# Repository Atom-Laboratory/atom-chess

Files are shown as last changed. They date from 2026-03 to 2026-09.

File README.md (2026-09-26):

# ATOM Chess

ATOM Chess is a research and development project focused on building an autonomous robotic chess system capable of perceiving a physical chessboard, analyzing the current game state, selecting a move, and physically executing it.

The project combines computer vision, chess programming, artificial intelligence, robotics, motion planning, and embedded systems into a single autonomous platform.

## ATOM Laboratory

ATOM Chess is part of **ATOM Laboratory**, a broader research and development initiative focused on the integration of robotics, computer vision, artificial intelligence, software engineering, electronics, and mechanical engineering.

ATOM Laboratory provides the broader research context in which ATOM Chess is developed. Other projects may be developed independently within the laboratory, with their own technical objectives, architectures, and licensing models.

ATOM Chess is one of the laboratory's open-source software projects, while its physical hardware remains proprietary unless explicitly released under a separate hardware license.

## Project Goals

The primary objective of ATOM Chess is to develop a self-contained robotic system capable of:

* Perceiving the physical chessboard through a camera.
* Determining the current board state.
* Detecting changes caused by human moves.
* Representing the position computationally.
* Generating a valid FEN representation.
* Querying a chess engine for the next move.
* Planning the required robotic motion.
* Executing the move on the physical board.
* Verifying the resulting board state.
* Recovering from unexpected situations.

The system is designed with modularity and hardware/software separation in mind, allowing individual subsystems to be developed, tested, and replaced independently.

## Project Leadership

ATOM Chess was conceived and initiated by **Enzo Ribas**, who leads the project’s technical and product development. He is responsible for defining the system architecture, coordinating the multidisciplinary development effort, and contributing across software engineering, computer vision, robotics, electronics, and mechanical systems.

For more information about his work and professional background, visit his [Enzo's LinkedIn profile](https://www.linkedin.com/in/oenzoribas/).

## System Architecture

ATOM Chess is organized into four primary subsystems:

### Vision

The vision subsystem is responsible for converting camera data into structured information about the chessboard.

### Chess Core

The chess core contains the domain model and game-state logic.

The core is intentionally independent of the physical robot and computer-vision implementation.

### Engine and Planning

The planning layer connects the chess domain to the robotic system.

The chess engine is treated as a decision component rather than as part of the board representation itself.

### Motion and Control

The motion subsystem is responsible for physically executing planned operations.

The current architecture separates high-level planning from low-level motor control, allowing computationally intensive logic to remain outside the microcontroller.

## Build

The project uses CMake as its build-system generator.

The supported development environment is Linux.

A typical build configuration is:

```bash
cmake -S . -B build
cmake --build build
```

Tests can be executed through the configured test target or CTest:

```bash
ctest --test-dir build
```

The exact build configuration may vary depending on the target platform and enabled components.

## Project Status

ATOM Chess is under active development.

Current development is focused on establishing a robust software foundation before integrating the complete perception, chess-engine, planning, and robotic-control pipeline.

The architecture is intentionally evolving as the individual subsystems are validated experimentally.

## Research

ATOM Chess is also intended as a research platform. Its modular architecture enables experimentation in areas including:

* Computer vision for structured environments.
* Chess position recognition.
* Automated move detection.
* Chess position representation.
* Chess-engine integration.
* Robotic manipulation.
* Motion planning.
* Inverse kinematics.
* Autonomous system architectures.
* Human-robot interaction.

The platform is designed so that individual components can be benchmarked and replaced without requiring a complete redesign of the system.

## Contributing

ATOM Chess is developed as a collaborative, multidisciplinary project involving software engineers, computer scientists, researchers, and contributors working across computer vision, chess programming, robotics, electronics, mechanical engineering, and related fields.

Contributions may include:

* Bug fixes.
* New features.
* Tests.
* Documentation.
* Refactoring.
* Performance improvements.
* Research implementations.
* Computer vision improvements.
* Chess algorithms.
* Robotics and motion-planning algorithms.

Pull requests should be focused, tested, and clearly describe the motivation, implementation, and testing performed.

All contributions are expected to follow the project's contribution guidelines, coding standards, testing requirements, and architectural conventions.

For information about contributing, see [`CONTRIBUTING.md`](CONTRIBUTING.MD).

Community members are also encouraged to review existing pull requests. Review guidelines and the community review template are available in [`.github/REVIEW_TEMPLATE.md`](.github/REVIEW_TEMPLATE.md).

## Licensing

ATOM Chess uses separate licensing for software and hardware.

### Software

The ATOM Chess software is released under the MIT License.

See [`LICENSE`](LICENSE) for the complete license text.

Unless explicitly stated otherwise, the MIT License applies to the software source code contained in this repository.

### Hardware

The ATOM Chess hardware is currently **not open source**.

Hardware designs are not licensed under the MIT License.

This includes, but is not limited to:

* Mechanical CAD files.
* Mechanical drawings.
* Electrical schematics.
* PCB designs.
* PCB layouts.
* Manufacturing files.
* Bills of materials.
* Assembly documentation.
* Manufacturing documentation.

Unless explicitly stated otherwise, no permission is granted to reproduce, manufacture, modify, distribute, or commercially exploit the ATOM Chess hardware designs.

See [`HARDWARE_LICENSE.md`](HARDWARE_LICENSE.md) for the current hardware licensing policy.

### Third-Party Materials

Third-party software, hardware, documentation, libraries, models, and other materials remain subject to their respective licenses.

The ATOM Chess MIT License does not supersede or replace the license of third-party materials.

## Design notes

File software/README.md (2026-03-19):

<div>

  <h1>Taxonomia</h1>
vision/
board_state/
engine/
motion/
robot/
integration/
config/
tests/

vision/
Tudo que envolve câmera, calibração, homografia, detecção de peças.

board_state/
Representação do tabuleiro. Conversão entre coordenadas de casa (E2) e coordenadas reais (x, y).

engine/
Interface com Stockfish. Nada de lógica física aqui. Só comunicação e interpretação de movimentos.

motion/
Planejamento de trajetórias. Conversão de coordenadas do mundo para pontos que a garra precisa visitar.

robot/
Drivers do SCARA. Comunicação serial, controle de motores, cinemática direta e inversa.

integration/
Onde o sistema todo conversa. Máquina de estados do robô. Aqui você decide: capturar imagem → validar → mover → confirmar.

config/
Parâmetros físicos:

– Altura da câmera
– Matriz de transformação câmera→garra
– Dimensões do tabuleiro
– Limites do SCARA

Nada de valores mágicos espalhados pelo código.

tests/
Testes unitários.
Teste de homografia.
Teste de cinemática inversa.
Teste de conversão casa→coordenada.

Agora algo que pouca gente faz e deveria fazer: versionar calibrações.

Crie uma pasta:

calibration_data/
</div>

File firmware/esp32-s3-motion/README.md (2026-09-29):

# ESP32-S3 Motion Controller Firmware

Reference firmware for the ATOM Chess adaptation of Dejan's How To Mechatronics SCARA.

It receives the host-side ACM1 joint contract:

```
ACM1|<seq>|SEG|<j1_rad>|<j2_rad>|<j3_rad>|<z_mm>|<gripper_pct>|<duration_ms>
```

and controls:

- J1 NEMA 17 through STEP/DIR;
- J2 NEMA 17 through STEP/DIR;
- J3 NEMA 17 through STEP/DIR;
- Z NEMA 17 through STEP/DIR;
- MG996R-compatible gripper servo.

## Safety default

`robot_config.hpp` ships with:

```cpp
configured = false;
```

In this state the firmware boots and parses protocol traffic but replies `ERR|100` to movement commands.

Do not change this flag until all physical values are measured.

## Before enabling motion

Fill:

- STEP/DIR GPIOs for J1/J2/J3/Z;
- endstop GPIOs;
- E-stop GPIO;
- servo GPIO;
- J1/J2/J3 steps per radian;
- Z steps per millimetre;
- motor direction inversion;
- speed/acceleration limits;
- servo pulse limits.

Record the same values in:

`software/acmotion/docs/physical-calibration-template.md`

## Build

Install PlatformIO, then:

```bash
cd firmware/esp32-s3-motion
pio run
pio run -t upload
pio device monitor -b 115200
```

## Bring-up order

1. Build with `configured=false`.
2. Verify serial boot message.
3. Verify endstop/E-stop inputs.
4. Measure and enter pin/conversion configuration.
5. Keep motor power disabled and verify ACM1 parsing.
6. Enable one driver/axis at a time at conservative current and speed.
7. Verify J1, then J2, then J3, then Z.
8. Verify gripper.
9. Verify E-stop/limit interruption.
10. Only then enable full host MotionExecution.

The firmware contains no chess-domain logic and no inverse kinematics.

## Runtime cancellation

Cancellation is polled during active motion, not only between segments.

A matching:

```
ACM1|<active-seq>|CANCEL
```

stops further STEP generation for the active segment and returns a terminal response. Additional SEG commands received while a segment is active are rejected rather than executed re-entrantly.

The physical E-stop must still be wired as an independent hardware safety mechanism; software cancellation is not a substitute for it.

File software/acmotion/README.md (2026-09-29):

# acmotion

`acmotion` is the high-level motion subsystem of ATOM Chess.

It runs primarily on the Linux SBC / Brain and converts validated chess moves into physically executable SCARA motion while keeping low-level motor control on the ESP32-S3.

## Runtime pipeline

```
ac::chess::Move
    ↓
TaskPlanner
    ↓
PhysicalTask[]
    ↓
MotionPlanner
    ↓
Pose[]
    ↓
InverseKinematics
    ↓
JointSegment[]
    ↓
MotionExecution
    ↓
ACM1 / IMotionTransport
    ↓
ESP32-S3
    ↓
interpolation / motion profile / STEP-DIR
```

## Component responsibilities

| Component | Responsibility | Runtime |
| --- | --- | --- |
| CoordinateMapper | Board/graveyard → calibrated XY | Linux SBC |
| GraveyardAllocator | Deterministic captured-piece slot allocation | Linux SBC |
| TaskPlanner | Validated Move → ordered PhysicalTask[] | Linux SBC |
| MotionPlanner | Physical transfer → safe Pose[] | Linux SBC |
| InverseKinematics | Pose → joint-space target | Linux SBC |
| MotionExecution | JointSegment sequencing and controller responses | Linux SBC |
| MotionProtocol | ACM1 encoding/parsing | Linux SBC + compatible firmware |
| ESP32-S3 firmware | Interpolation, profiles, STEP/DIR, limits, E-stop | ESP32-S3 |

## Documentation

Start here for physical integration:

- [Dejan SCARA bring-up manual](docs/dejan-scara-bringup.md)
- [Physical integration runbook](docs/physical-integration-runbook.md)
- [Physical calibration template](docs/physical-calibration-template.md)

Architecture decisions:

- [ADR-002 — SBC/ESP32 boundary](../docs/adrs/ADR-002-acmotion-sbc-esp32-boundary.md)
- [ADR-003 — TaskPlanner/PhysicalTask boundary](../docs/adrs/ADR-003-task-planner-physical-task-boundary.md)
- [ADR-004 — IK on SBC](../docs/adrs/ADR-004-inverse-kinematics-on-sbc.md)
- [ADR-005 — ACM1 protocol](../docs/adrs/ADR-005-acm1-motion-protocol.md)

## Linux quick start

From repository root:

```bash
bash software/acmotion/scripts/setup_linux.sh
bash software/acmotion/scripts/build_and_test.sh
bash software/acmotion/scripts/preflight_linux.sh
```

For a specific serial device:

```bash
bash software/acmotion/scripts/preflight_linux.sh /dev/ttyUSB0
python3 software/acmotion/scripts/serial_monitor.py \
  --device /dev/ttyUSB0 \
  --baud 115200
```

The serial monitor is intentionally read-only.

## Build without ROS2

ROS2/ament remains optional for the MVP motion core.

Repository headless build:

```bash
cmake -S . -B build -G Ninja \
  -DCMAKE_BUILD_TYPE=Debug \
  -DACCHESS_BUILD_VIEWER=OFF \
  -DACVISION_BUILD_HARDWARE_TESTS=OFF

cmake --build build --parallel
ctest --test-dir build --output-on-failure
```

## Rules for contributors

- Do not introduce production mocks into runtime motion code.
- Do not duplicate chess legality in `acmotion`.
- Do not put FEN, Board, PieceType or chess-square semantics in ESP32 firmware.
- Do not hard-code physical SCARA dimensions in the IK solver.
- Do not bypass CoordinateMapper with duplicated physical board constants.
- Keep units explicit in public APIs and Doxygen.
- Hardware-independent tests must remain runnable on CI.
- New hardware/protocol decisions should receive an ADR.

## How To Mechatronics compatibility

The selected physical arm is Dejan's How To Mechatronics SCARA design with J1, J2, J3 and Z driven by four NEMA 17 motors plus an MG996R gripper servo.

The acmotion joint-space contract now represents all four NEMA-driven axes. `Pose.toolYawRad` defines planar end-effector orientation; inverse kinematics solves J1/J2 for XY and derives J3 to maintain that orientation. ACM1 transports J1/J2/J3/Z/gripper.

Physical dimensions, J3 zero offset, joint limits, transmission ratios and motor-direction conventions remain hardware calibration values and must be measured before powered autonomous motion.

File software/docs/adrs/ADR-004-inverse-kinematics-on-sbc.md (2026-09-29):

# ADR-004: Inverse kinematics runs on the Linux SBC

## Status

Proposed for #153 / PR #156.

## Context

The SCARA manipulator requires conversion from Cartesian end-effector poses into joint-space targets before low-level execution.

Placing inverse kinematics in the ESP32 firmware would couple manipulator geometry, frame conventions and workspace policy to the embedded controller. That would make simulation, numerical testing and future geometry changes harder.

## Decision

Run inverse kinematics on the Linux SBC / Brain.

The SBC converts:

```
Pose(x, y, z, gripper, toolYaw)
    ↓
InverseKinematics
    ↓
JointTarget(theta1, theta2, theta3, z, gripper)
```

The ESP32-S3 receives joint-space targets only.

### Geometry

The solver is parameterized by:
- link 1 length in millimetres;
- link 2 length in millimetres;
- joint 1 angular limits in radians;
- joint 2 angular limits in radians;
- joint 3 angular limits in radians;
- joint 3 zero offset in radians;
- Z travel limits in millimetres;
- deterministic elbow configuration.

No project-specific physical dimensions are hard-coded in the solver.

### Model

The planar 2R solution uses:

```
c2 = (x² + y² - L1² - L2²) / (2 L1 L2)
theta2 = ±acos(c2)
theta1 = atan2(y, x) - atan2(L2 sin(theta2), L1 + L2 cos(theta2))
```

The selected elbow branch is explicit and deterministic.

For the distal axis:

```
theta3 = toolYaw - theta1 - theta2 - joint3ZeroOffset
```

This keeps the planar end-effector/camera orientation explicit and independent from the J1/J2 position solution.

## Coordinate-frame assumptions

Before physical use, the team must document and measure:
- SCARA base origin;
- positive X direction;
- positive Y direction;
- positive joint rotation conventions;
- zero/reference angle of each revolute joint;
- positive Z direction;
- tool-center-point offset, if any;
- board plane height relative to Z zero.

These values are hardware configuration, not implementation constants.

## Consequences

IK is testable numerically without the robot.

Manipulator geometry can change without modifying firmware protocol semantics.

The firmware remains simpler and deterministic.

Incorrect frame definitions or CAD measurements can still produce physically unsafe targets, so integration must begin with motor power disabled and then progress through low-speed joint validation.

## Physical validation sequence

1. Measure L1/L2 and joint zero references.
2. Record mechanical joint and Z limits.
3. Validate solver against hand-computed/reference points.
4. With motors disabled, compare generated targets against expected joint values.
5. Enable one axis at low speed.
6. Validate both revolute axes independently.
7. Validate combined planar moves.
8. Validate Z.
9. Only then test full Cartesian pick-and-place trajectories.

## Related

- #56
- #58
- #153
- #156

## Joint 3 orientation policy for the selected arm

The selected How To Mechatronics SCARA includes a third revolute joint at the distal arm/end-effector. ATOM therefore treats tool yaw as part of the Cartesian pose.

J1/J2 solve XY position. J3 compensates the accumulated J1/J2 rotation so the requested tool/camera yaw is maintained relative to the SCARA base frame.

The physical zero offset and J3 limits remain calibration data, not hard-coded geometry.

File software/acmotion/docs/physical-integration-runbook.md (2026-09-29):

# acmotion — Physical Integration Runbook

This runbook is the operational guide for bringing the ATOM Chess motion stack from a clean Linux SBC to the first controlled SCARA movements.

It complements the architectural decisions in:

- `software/docs/adrs/ADR-002-acmotion-sbc-esp32-boundary.md`
- `software/docs/adrs/ADR-003-task-planner-physical-task-boundary.md`
- `software/docs/adrs/ADR-004-inverse-kinematics-on-sbc.md`
- `software/docs/adrs/ADR-005-acm1-motion-protocol.md`

## 1. Safety prerequisites

Before powering motor drivers:

- secure the SCARA base mechanically;
- verify the emergency-stop circuit independently of software;
- verify limit/endstop wiring;
- set DRV8825 current limits according to the actual motors;
- keep the 12 V motor rail disconnected during protocol-only testing;
- verify common ground between the SBC/ESP32 logic and motor-control electronics;
- ensure the Z axis cannot fall freely when power is removed;
- establish a clear physical emergency-stop procedure.

Software tests do not replace electrical/mechanical safety checks.

## 2. Supported Linux workflow

The core motion stack is designed to build on a headless Linux SBC without ROS2.

Recommended environment:

- Ubuntu 24.04 / Armbian based on Ubuntu 24.04;
- CMake >= 3.23;
- Ninja;
- GCC or Clang;
- Git;
- Python 3 for serial diagnostics;
- Stockfish/OpenCV may still be required by the repository-wide build.

From the repository root:

```bash
bash software/acmotion/scripts/setup_linux.sh
bash software/acmotion/scripts/build_and_test.sh
```

The second script performs a headless repository build and executes CTest.

## 3. Verify acmotion without hardware

Run the module-focused test subset:

```bash
ctest --test-dir build --output-on-failure -R "motion|task|graveyard|coordinate|inverse"
```

Expected before hardware integration:

- CoordinateMapper tests pass;
- GraveyardAllocator tests pass;
- TaskPlanner tests pass;
- MotionPlanner tests pass;
- MotionProtocol tests pass;
- MotionExecution tests pass;
- InverseKinematics tests pass.

## 4. Record physical robot geometry

Do not edit source code to insert real robot dimensions.

Record the measured/CAD values in your hardware configuration source:

- link 1 length, mm;
- link 2 length, mm;
- joint 1 minimum/maximum, rad;
- joint 2 minimum/maximum, rad;
- joint 3 minimum/maximum, rad;
- joint 3 zero offset, rad;
- Z minimum/maximum, mm;
- joint zero/reference positions;
- selected elbow configuration;
- tool-center-point offset, if present.

The current IK API expects these values through `ScaraGeometry`.

## 5. Establish the SCARA coordinate frame

Before board calibration, document:

- base-frame origin;
- +X direction;
- +Y direction;
- +Z direction;
- positive joint-1 rotation;
- positive joint-2 rotation;
- positive joint-3 rotation;
- tool yaw zero/orientation convention;
- board plane Z;
- gripper/tool-center reference.

Use one convention consistently in:

- CAD;
- CoordinateMapper calibration;
- IK configuration;
- firmware motor direction;
- integration logs.

If one layer inverts an axis independently, physical targets will be wrong even when unit tests pass.

## 6. Calibrate the chessboard

CoordinateMapper assumes a fixed board relative to the SCARA.

Measure and store:

- A1 physical coordinate;
- H1 physical coordinate;
- board orientation/rank direction;
- graveyard origins;
- graveyard row/column steps.

Validate several known squares before attempting a pick:

```
a1
h1
a8
h8
e4
```

The measured physical position should match the mapped point within the mechanical tolerance accepted by the project.

## 7. Validate IK offline

Before connecting the ESP32:

1. create `ScaraGeometry` from measured values;
2. solve known Cartesian points;
3. independently calculate or measure expected joint angles;
4. reject points outside the physical workspace;
5. verify J1/J2/J3 limits, requested tool yaw, and Z limits.

Do not use the default values from unit tests as robot configuration. They are synthetic fixtures only.

## 8. Prepare Linux serial access

List serial devices:

```bash
ls -l /dev/ttyUSB* /dev/ttyACM* 2>/dev/null || true
```

Check group ownership:

```bash
stat -c '%n %U %G %a' /dev/ttyUSB0
```

On Debian/Ubuntu systems, serial devices are commonly assigned to `dialout`.

If required:

```bash
sudo usermod -aG dialout "$USER"
```

Log out and back in after changing group membership.

Do not use `chmod 777` as a persistent serial-device fix.

## 9. Protocol-only bring-up

Keep motor power disabled.

Run the read-only serial monitor:

```bash
python3 software/acmotion/scripts/serial_monitor.py \
  --device /dev/ttyUSB0 \
  --baud 115200
```

Then reset the ESP32-S3 and inspect startup/protocol lines.

Expected runtime protocol is documented in ADR-005.

Do not send movement commands until:

- parser framing is verified;
- sequence IDs are echoed correctly;
- ACK/DONE semantics are implemented;
- ERR/ESTOP/LIMIT can be observed.

## 10. First powered test

Use conservative settings:

- low motor current appropriate for safe bench testing;
- low velocity;
- low acceleration;
- one axis at a time;
- no chess pieces;
- no camera dependency;
- operator within reach of hardware E-stop.

Test order:

1. joint 1 small positive/negative move;
2. joint 2 small positive/negative move;
3. joint 3 small positive/negative move;
4. Z small positive/negative move;
5. gripper open/close;
6. each limit switch independently;
7. emergency stop during motion;
8. J1/J2/J3 coordinated orientation check;
9. Cartesian point + tool yaw produced through IK;
10. board-square approach with gripper open;
11. only then test pick-and-place.

## 11. First board transfer

Use a single disposable/test piece and a central board square.

Recommended sequence:

1. map source/target with CoordinateMapper;
2. TaskPlanner produces one PhysicalTask;
3. MotionPlanner expands it to Pose[];
4. IK converts every Pose to joint targets;
5. inspect/log all targets before execution;
6. MotionExecution sends segments;
7. firmware returns ACK/DONE for each segment;
8. verify the final physical position manually.

Do not begin with captures, graveyard movements or castling.

## 12. Special-move validation order

After simple transfers are repeatable:

1. normal capture;
2. graveyard allocation;
3. en passant;
4. castling;
5. promotion strategy only after physical replacement mechanics are defined.

## 13. Logging checklist

For every physical integration failure, capture:

- Git commit SHA;
- SBC model and OS version;
- ESP32 firmware version/commit;
- serial device and baud;
- ScaraGeometry values;
- CoordinateMapper calibration values;
- JointSegment sequence;
- raw ACM1 command;
- raw controller response;
- E-stop/limit state;
- motor power/current configuration;
- observed physical behavior.

This information should accompany hardware-related GitHub issues.

## 14. Definition of physical integration readiness

The motion stack is ready for end-to-end MVP integration when:

- repository CI is green;
- coordinate calibration is repeatable;
- IK is validated against measured geometry;
- serial transport is stable;
- ACK/DONE/ERR/ESTOP/LIMIT are implemented on firmware;
- one-axis and multi-axis tests pass;
- simple pick-and-place is repeatable;
- capture/graveyard flow works;
- emergency stop reliably enters a safe physical state.

Only after these checks should the Game Coordinator/FSM own autonomous execution.

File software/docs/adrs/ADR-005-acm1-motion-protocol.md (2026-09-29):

# ADR-005: Versioned ACM1 protocol and transport abstraction

## Status

Proposed for #154 / PR #155.

## Context

The Linux SBC must send joint-space motion segments to the ESP32-S3 while remaining independent of a specific serial library or device path.

The protocol must be simple enough to inspect during bring-up, explicit about sequence ownership, and robust enough to distinguish successful completion from timeout, controller error, emergency stop and limit-switch events.

## Decision

Use a versioned, line-delimited ASCII protocol named ACM1 for the MVP.

### Commands

Segment:

```
ACM1|<seq>|SEG|<j1_rad>|<j2_rad>|<j3_rad>|<z_mm>|<gripper_pct>|<duration_ms>
```

Cancellation:

```
ACM1|<seq>|CANCEL
```

### Responses

```
ACM1|<seq>|ACK
ACM1|<seq>|DONE
ACM1|<seq>|ERR|<code>
ACM1|<seq>|ESTOP
ACM1|<seq>|LIMIT
```

### Sequence semantics

- sequence IDs are non-zero;
- host trajectory sequence IDs are strictly increasing;
- every SEG requires an ACK before execution is considered accepted;
- every accepted SEG requires DONE before the host advances to the next segment;
- a response for the wrong sequence is a protocol error;
- timeout is never treated as success;
- ESTOP and LIMIT force host SafeStop state.

### Transport abstraction

`MotionExecution` depends on `IMotionTransport`, not directly on UART/termios.

This enables:
- deterministic fake transport tests;
- Linux UART implementation later;
- USB CDC or socket transports if needed;
- protocol testing without powered motors.

## Why ASCII for MVP

ASCII is intentionally chosen for the first hardware integration because it:
- is easy to inspect with terminal tools;
- reduces firmware parser complexity;
- makes logs directly readable;
- allows protocol bring-up before binary framing is necessary.

A future binary protocol may supersede ACM1 if throughput or integrity requirements demand it. That requires a new ADR/version.

## Consequences

Host code can be validated before firmware is complete.

Firmware does not need chess or Cartesian types.

The protocol does not currently define checksums, retries or streaming windows. Those are intentionally deferred until real serial measurements show they are necessary.

## Bring-up rule

Do not start with motor power enabled.

First validate:
1. Linux device permissions;
2. baud/framing configuration;
3. line parsing;
4. sequence matching;
5. ACK/DONE;
6. ERR/ESTOP/LIMIT;
7. cancel behavior;
8. then enable low-current/low-speed motion.

## Related

- #56
- #58
- #154
- #155

## Joint 3 field

ACM1 segment frames include J1, J2, J3, Z and gripper. Because no production firmware had been frozen when J3 support was added, the MVP retained the ACM1 version while extending the SEG payload.

Any future incompatible framing change should increment the protocol version.

## Cancellation during execution

The ESP32-S3 parser must remain responsive to `CANCEL` while a segment is active. The reference firmware polls serial input inside the active-motion loop and rejects re-entrant SEG commands.

Software cancellation is operational control, not the primary safety mechanism. E-stop must remain independently wired at the hardware level.

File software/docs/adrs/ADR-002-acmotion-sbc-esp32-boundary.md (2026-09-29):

# ADR-002: acmotion boundaries and SBC/ESP32 responsibility split

## Status

Proposed for the acmotion integration chain (#152, #155, #156).

## Context

ATOM Chess is distributed across Linux SBCs and an ESP32-S3. The motion stack must remain testable on Linux without robot hardware while preserving deterministic low-level control on the microcontroller.

Mixing chess semantics, Cartesian planning, inverse kinematics and STEP/DIR control in the same runtime would increase coupling, make hardware testing harder and complicate fault recovery.

## Decision

Split motion responsibilities at the joint-space execution boundary.

### Linux SBC / Brain

The SBC owns:
- `TaskPlanner`;
- `CoordinateMapper`;
- `GraveyardAllocator`;
- `MotionPlanner`;
- Cartesian `Pose` generation;
- inverse kinematics;
- `JointSegment` construction;
- `MotionExecution`;
- protocol sequencing, timeout and high-level recovery decisions.

### ESP32-S3

The ESP32-S3 owns:
- ACM1 command parsing;
- segment buffering;
- interpolation;
- velocity/acceleration motion profiles;
- conversion from joint targets to STEP/DIR;
- motor synchronization;
- Z-axis and gripper low-level actuation;
- endstop / limit input;
- emergency-stop handling;
- ACK / DONE / ERR / ESTOP / LIMIT responses.

### Boundary rule

The firmware must not depend on:
- FEN;
- `Board`;
- `Move`;
- `PieceType`;
- chess `Square`;
- graveyard allocation policy;
- Cartesian inverse-kinematics decisions.

The host must not generate individual STEP pulses or directly encode DRV8825 timing policy.

## Consequences

The Linux motion core can be unit-tested without hardware.

The ESP32 firmware can be tested against joint-space protocol fixtures without linking chess or computer-vision code.

Physical integration becomes a contract test between `JointSegment` and the firmware rather than an implicit coupling between modules.

Changing the manipulator geometry requires updating SBC-side configuration and IK, not chess-domain or firmware semantics.

## Integration checks

Before connecting motors:
1. verify host build/tests;
2. verify coordinate-frame conventions;
3. verify IK with measured dimensions;
4. verify protocol over serial with motor power disabled;
5. verify endstop/E-stop responses;
6. only then enable drivers and perform low-speed joint tests.

## Related

- #56
- #58
- #152
- #153 / #156
- #154 / #155

## Physical-arm compatibility note

The chosen How To Mechatronics SCARA has J1, J2, J3 and Z as NEMA-17-driven DOFs, plus a servo gripper. The current software boundary must be extended to carry Joint 3 before autonomous physical execution. See #160.

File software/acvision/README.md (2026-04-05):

# 📷 ATOM Chess — Visão Computacional

## 📋 Sumário

1. [Requisitos de Sistema](#-1-requisitos-de-sistema)  
2. [OpenCV (Windows)](#️-2-opencv-windows)  
3. [Configuração do Ambiente (MSVC)](#️-3-configuração-do-ambiente-msvc)  
4. [Build e Execução via Terminal](#-4-build-e-execução-via-terminal)  
5. [Fluxo Diário de Desenvolvimento](#-5-fluxo-diário-de-desenvolvimento)  
6. [Troubleshooting](#-6-troubleshooting)

---

## 🧩 1. Requisitos de Sistema

### Windows

- Visual Studio Build Tools 2022 (C++)
- CMake instalado no `PATH`
- Ninja (opcional)
- VSCode como editor

**Extensão recomendada:**

- C/C++ (Microsoft)

### Linux

#### Debian Distributions:

```bash
sudo apt update
sudo apt install build-essential cmake ninja-build libopencv-dev
```

#### Arch:

```bash
sudo pacman -Syu
pacman -S --needed base-devel cmake ninja opencv
```

---

## 🛠️ 2. OpenCV (Windows)

Baixe o OpenCV pré-compilado e extraia em:

```text
D:\opencv
```

Verifique se existe:

```text
D:\opencv\build\x64\vc16\lib\OpenCVConfig.cmake
```

### Variável de ambiente (`OpenCV_DIR`)

```bat
setx OpenCV_DIR "D:\opencv\build\x64\vc16"
```

Adicione também ao `PATH`:

```text
D:\opencv\build\x64\vc16\bin
```

> Reinicie o terminal após essas alterações.

---

## ⚙️ 3. Configuração do Ambiente (MSVC)

Antes de compilar, no cmd, execute:

```bat
"C:\Program Files\Microsoft Visual Studio\18\Community\VC\Auxiliary\Build\vcvars64.bat"
```

Teste com:

```bat
cl
```

Se a versão do compilador aparecer, está correto.

### 📁 Estrutura do projeto

```text
Software/acvision/
├── CMakeLists.txt
├── src/
├── include/
└── build/
```

---

## 🔨 4. Build e Execução via Terminal

Entre no projeto:

```bat
cd Software/acvision
```

Configure:

```bat
cmake --preset debug
```

Compile:

```bat
cmake --build build
```

Localize o executável:

```bat
dir build /s *.exe
```

Execute:

```bat
build\Debug\nome_do_executavel.exe
```

---

## 🚀 5. Fluxo Diário de Desenvolvimento

Sempre que abrir o projeto:

```bat
"C:\Program Files\Microsoft Visual Studio\18\Community\VC\Auxiliary\Build\vcvars64.bat"
cd Software/acvision
cmake --build build
build\Debug\nome_do_executavel.exe
```

---

## 🧪 6. Troubleshooting

### `cl` não reconhecido

MSVC não foi carregado. Execute `vcvars64.bat`.

### `OpenCV_DIR` errado

Deve apontar para a pasta que contém `OpenCVConfig.cmake`.

### Erro de DLL do OpenCV

Adicione ao `PATH`:

```text
D:\opencv\build\x64\vc16\bin
```

### Erro `LNK` / `cv::`

Compilador incorreto. Use **MSVC (`cl.exe`)**, nunca MinGW.

### `cmake` não encontrado

CMake não está no `PATH` do sistema.

---

## ✅ Regra final

Não usar **CMake Tools** do VSCode.  
Todo build deve ser feito via terminal com MSVC ativo.

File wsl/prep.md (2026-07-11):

sudo apt update && sudo apt install locales software-properties-common curl -y
sudo locale-gen en_US en_US.UTF-8
sudo update-locale LC_ALL=en_US.UTF-8 LANG=en_US.UTF-8
export LANG=en_US.UTF-8

sudo add-apt-repository universe -y
sudo curl -sSL https://raw.githubusercontent.com/ros/rosdistro/master/ros.key -o /usr/share/keyrings/ros-archive-keyring.gpg
echo "deb [arch=$(dpkg --print-architecture) signed-by=/usr/share/keyrings/ros-archive-keyring.gpg] http://packages.ros.org/ros2/ubuntu $(. /etc/os-release && echo $UBUNTU_CODENAME) main" | sudo tee /etc/apt/sources.list.d/ros2.list > /dev/null

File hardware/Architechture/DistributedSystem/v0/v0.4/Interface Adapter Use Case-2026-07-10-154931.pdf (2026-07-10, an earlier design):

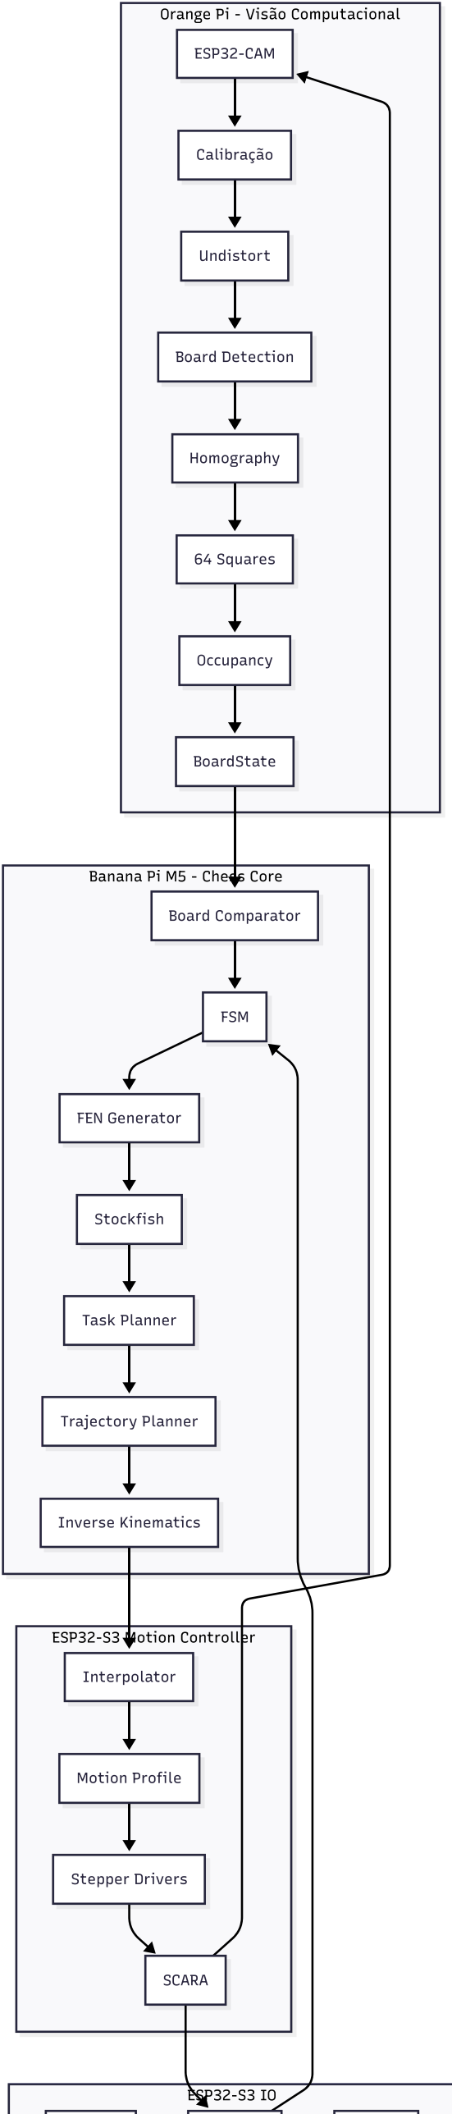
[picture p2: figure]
ESP32-S3 IO; ESP32-S3 Motion Controller; Banana Pi M5 - Chess Core; Orange Pi - Visão Computacional; ESP32-CAM; Calibração; Undistort; Board Detection; Homography; 64 Squares; Occupancy; BoardState; FSM; Board Comparator; FEN Generator; Stockfish; Task Planner; Trajectory Planner; Inverse Kinematics; Interpolator; Motion Profile; Stepper Drivers; SCARA

Gripper | Sensors | Status

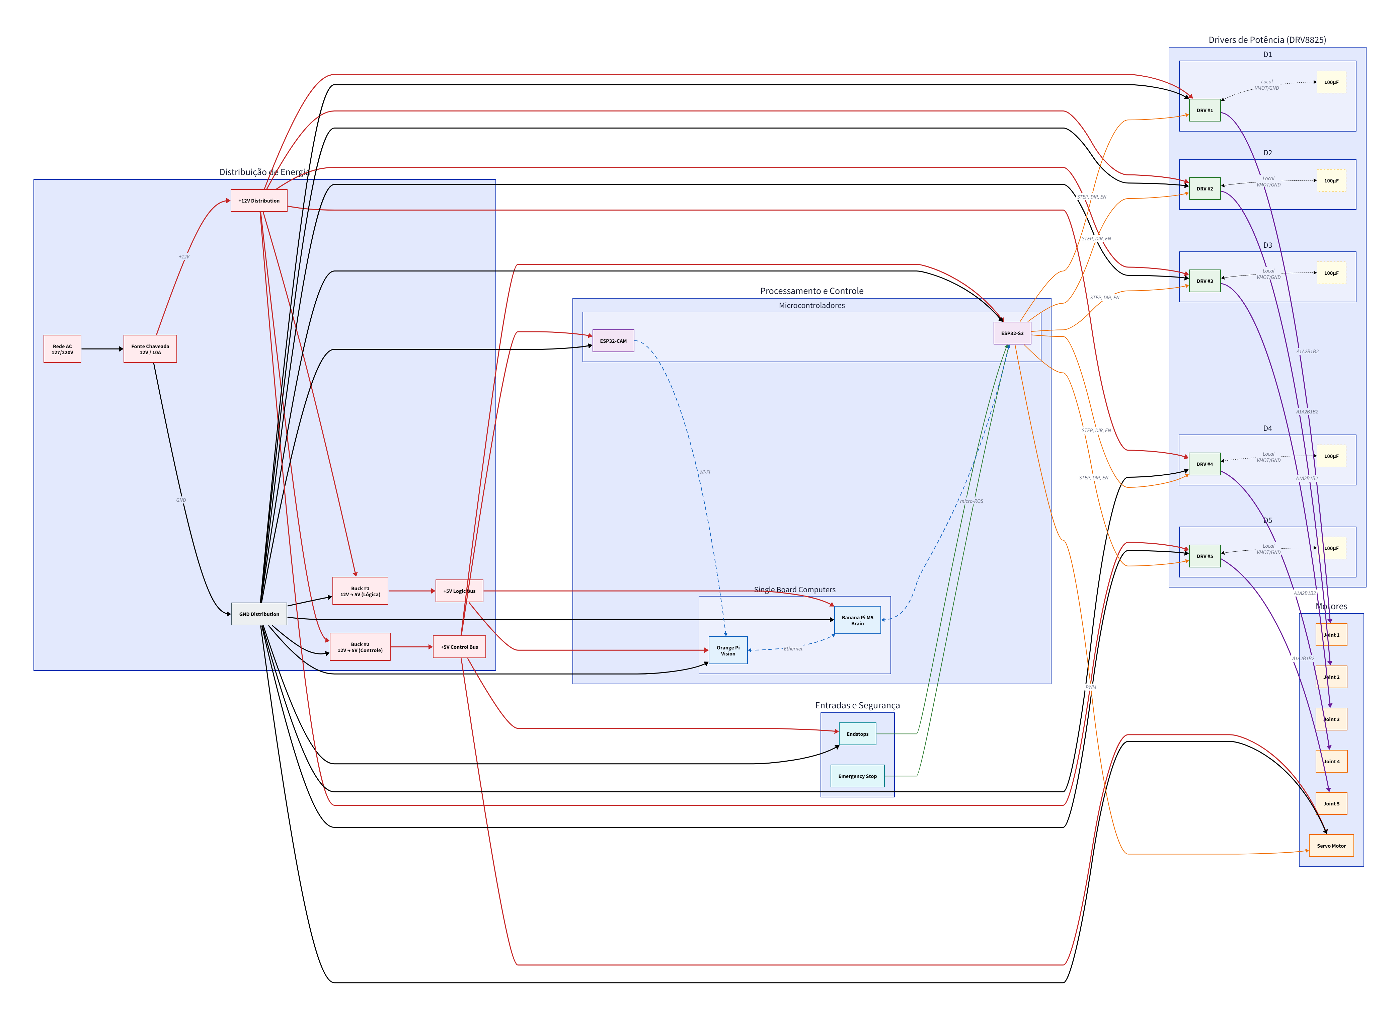
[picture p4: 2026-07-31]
hardware/Architechture/Eletronic/v0.0/v0.0 eletronic diagram.png

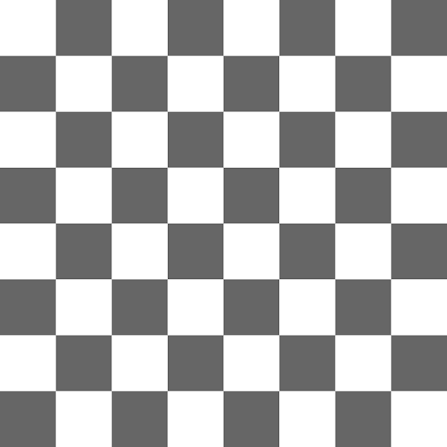
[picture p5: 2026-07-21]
software/acchess/assets/board.png

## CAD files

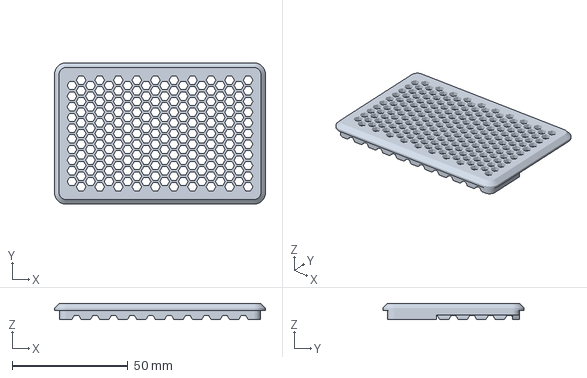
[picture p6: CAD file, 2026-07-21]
hardware/Project/Banana Pi M5 case/BananaPi M5 Case Lid.3mf
91.0 x 61.0 x 7.00 mm

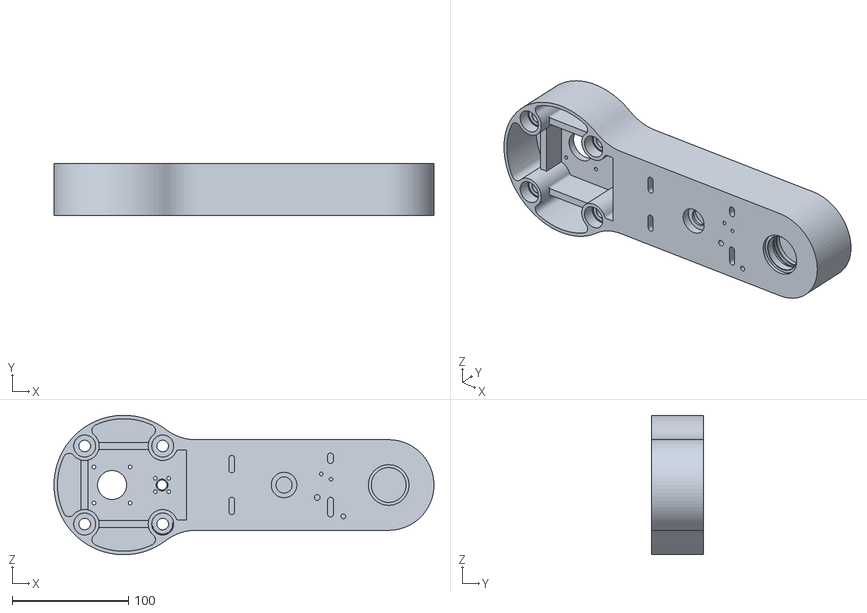
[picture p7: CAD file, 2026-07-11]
simulation/src/atom_description/meshes/arm1.stl
327.0 x 45.0 x 120.0

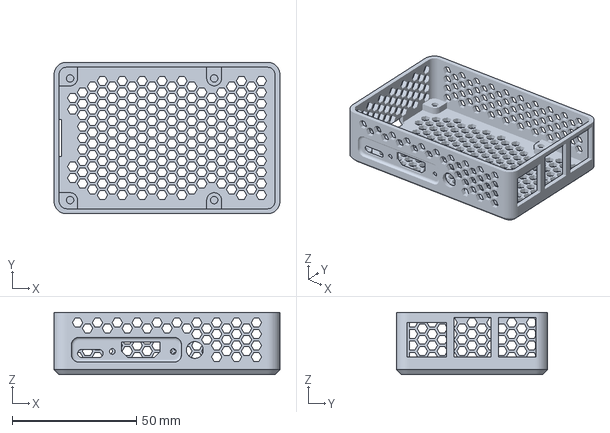
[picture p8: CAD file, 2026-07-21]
hardware/Project/Banana Pi M5 case/BananaPi M5 Case.3mf
91.0 x 61.0 x 25.0 mm

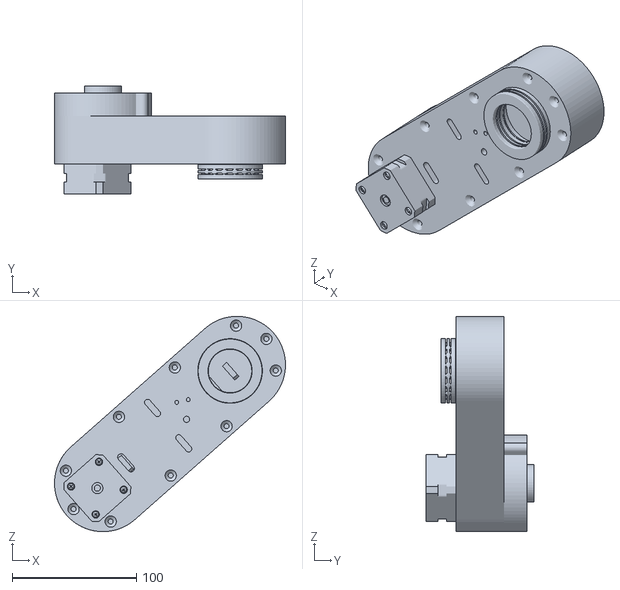
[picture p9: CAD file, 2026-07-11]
simulation/src/atom_description/meshes/arm2.stl
185.9 x 87.0 x 173.3

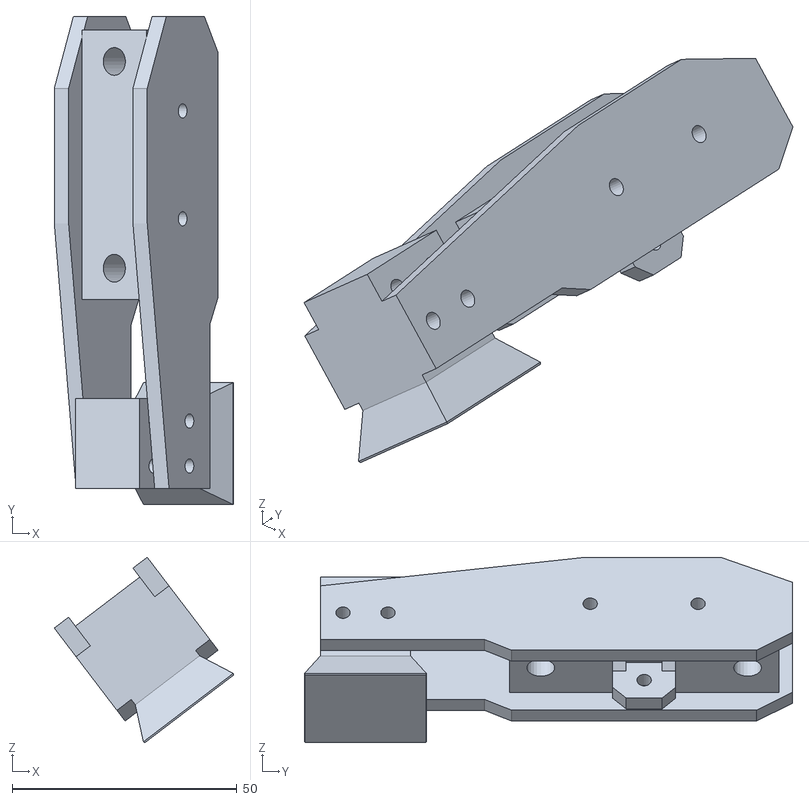
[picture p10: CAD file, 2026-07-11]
simulation/src/atom_description/meshes/gripper_hand1.stl
39.9 x 108.6 x 41.3

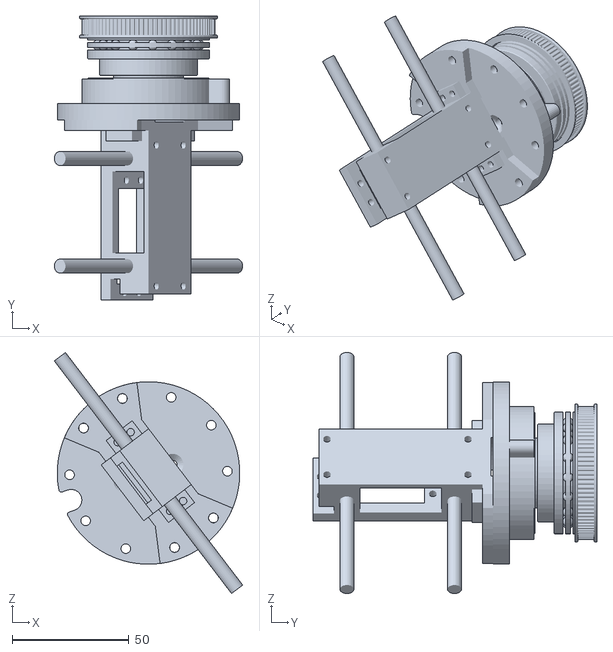
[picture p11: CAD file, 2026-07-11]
simulation/src/atom_description/meshes/gripper_back.stl
80.5 x 121.4 x 103.1

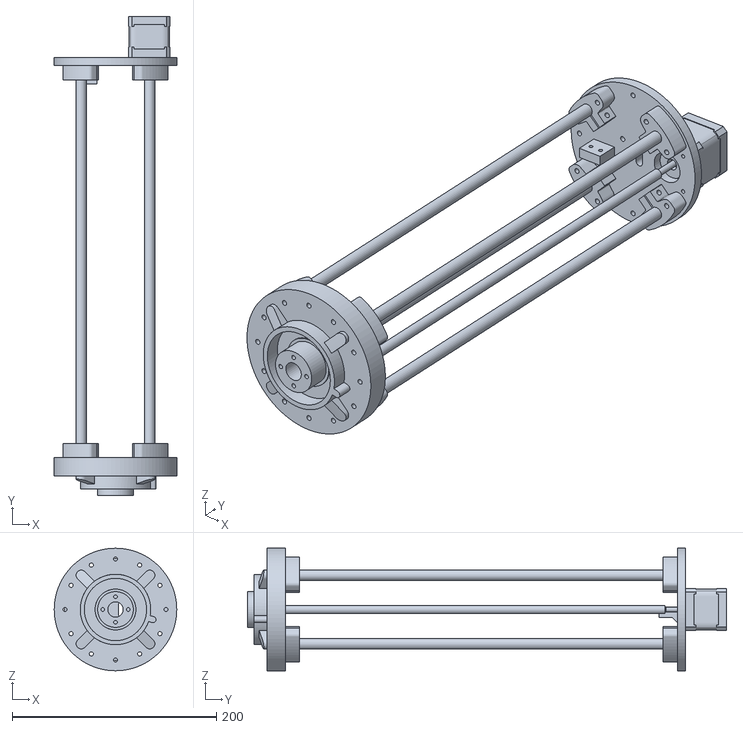
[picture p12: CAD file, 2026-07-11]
simulation/src/atom_description/meshes/z_axis.stl
120.0 x 469.0 x 120.0

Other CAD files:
simulation/install/atom_description/share/atom_description/meshes/base.stl
simulation/src/atom_description/meshes/gripper_hand2.stl
simulation/install/atom_description/share/atom_description/meshes/gripper_back.stl
simulation/install/atom_description/share/atom_description/meshes/arm1.stl
simulation/install/atom_description/share/atom_description/meshes/gripper_hand1.stl
simulation/install/atom_description/share/atom_description/meshes/z_axis.stl
simulation/install/atom_description/share/atom_description/meshes/arm2.stl
simulation/install/atom_description/share/atom_description/meshes/gripper_hand2.stl

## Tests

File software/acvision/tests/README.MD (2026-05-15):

# Testes do modulo acvision

Esta pasta concentra os testes automatizados do modulo de visao computacional.
O objetivo principal e validar o comportamento do `BoardDetector` com imagens 2D
reprodutiveis, sem depender de uma webcam conectada ao ambiente de teste.

## Estrutura

- `test_camera.cpp`: teste de integracao simples para captura de camera. Depende de hardware.
- `test_board_detector.cpp`: testes unitarios/reprodutiveis para deteccao de tabuleiro.
- `images/`: assets 2D usados pelos testes do detector.

## Imagens esperadas

Os testes do `BoardDetector` usam os seguintes arquivos:

- `images/chessboard.png`: imagem com um tabuleiro de xadrez 8x8 visivel.
- `images/no_board.png`: imagem 2D sem tabuleiro.

Esta pasta ja inclui imagens sinteticas deterministicas geradas com OpenCV. Elas
sao pequenas, versionaveis e podem ser substituidas por capturas reais 2D no
futuro, desde que mantenham os mesmos nomes. Se os arquivos forem removidos, o
teste tenta recria-los antes de carrega-los com `cv::imread`.

## Como rodar

A partir de `Software/acvision`:

```sh
mkdir -p build
cd build
cmake ..
make -j$(nproc)
ctest --output-on-failure
```

Para rodar apenas o teste do detector:

```sh
ctest -R test_board_detector --output-on-failure
```

## Por que imagens 2D

Testes com imagens 2D sao reprodutiveis, rapidos e independentes de camera,
iluminacao, foco, permissao de dispositivo e disponibilidade de hardware. A camera
continua util para validacao manual e testes de integracao, mas nao deve ser a base
dos testes unitarios do detector.

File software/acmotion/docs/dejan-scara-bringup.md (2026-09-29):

# ATOM Chess — Bring-up manual for Dejan / How To Mechatronics SCARA

This guide is specific to the SCARA robot from the How To Mechatronics tutorial by Dejan and the ATOM Chess electronics/software architecture.

Official mechanical reference:
https://howtomechatronics.com/projects/scara-robot-how-to-build-your-own-arduino-based-robot/

## 0. Software compatibility status

The reference robot uses:

- Joint 1 — NEMA 17 rotational axis;
- Joint 2 — NEMA 17 rotational axis;
- Joint 3 — NEMA 17 rotational/distal axis;
- Z axis — NEMA 17 + lead screw;
- gripper — MG996R servo.

ATOM's motion contract now represents J1/J2/J3/Z plus the servo gripper.

For chess, the SBC uses `Pose.toolYawRad` as the desired planar end-effector orientation. IK solves J1/J2 for XY and computes J3 so the requested yaw is maintained after applying the measured J3 zero offset.

Before powered autonomous motion, you still must measure and configure:
- J1/J2/J3 mechanical limits;
- J3 zero offset;
- all transmission ratios / steps-per-radian;
- Z steps/mm and limits;
- motor direction conventions;
- physical board calibration.

---

# 1. Mechanical inspection

Before electronics:

1. Check all printed parts for cracks.
2. Check that all three rotary joints move freely by hand.
3. Tension GT2 belts without over-tensioning bearings.
4. Check pulley set screws.
5. Verify there is no mechanical collision across the intended work area.
6. Verify the Z carriage moves freely along the rods.
7. Turn the lead screw manually through the intended Z range.
8. Verify the gripper can open/close without binding.
9. Keep the chessboard out of the workspace for the first powered tests.

Record backlash in each belt-driven joint.

Do not try to compensate backlash in software before measuring it.

---

# 2. Identify and label every actuator

Label connectors physically before connecting drivers.

Recommended labels:

```
M1 = Joint 1
M2 = Joint 2
M3 = Joint 3
M4 = Z axis
S1 = gripper servo
LS1 = Joint 1 reference/endstop
LS2 = Joint 2 reference/endstop
LS3 = Joint 3 reference/endstop
LSZ = Z reference/endstop
```

Use the same names in firmware, wiring diagrams, logs and calibration records.

---

# 3. ATOM electronics architecture

The original tutorial uses Arduino UNO + CNC Shield + A4988 drivers.

ATOM replaces the control architecture with:

```
Banana Pi / Linux SBC
        |
        | USB/UART - ACM protocol
        v
ESP32-S3
        |
        +--> DRV8825 J1 --> NEMA 17
        +--> DRV8825 J2 --> NEMA 17
        +--> DRV8825 J3 --> NEMA 17
        +--> DRV8825 Z  --> NEMA 17
        |
        +--> servo output --> MG996R gripper
        |
        +<-- endstops / E-stop
```

The Linux SBC performs high-level planning and IK.

The ESP32-S3 performs deterministic motor execution.

---

# 4. Power architecture

Use separate power domains conceptually:

## Motor rail

12 V supply → DRV8825 VMOT.

## Logic rail

Stable regulated logic supply → ESP32-S3.

## Servo rail

Use a suitable regulated supply for the MG996R.

Do not power the MG996R directly from a weak MCU regulator.

All control-domain grounds that exchange STEP/DIR/PWM signals must share a valid reference ground.

Before connecting motors:

1. disconnect motor power;
2. verify supply polarity;
3. verify 12 V rail;
4. verify logic supply;
5. verify servo supply;
6. verify common ground;
7. check for shorts with a multimeter.

---

# 5. DRV8825 preparation

For each axis:

1. install the driver with correct orientation;
2. install the bulk capacitor close to VMOT/GND;
3. configure microstepping consistently;
4. leave motor disconnected initially;
5. set the current limit before sustained motion.

Do not copy a current-limit value blindly.

Use the actual NEMA 17 rated phase current and the specific DRV8825 carrier-board sense resistor/calibration.

Record the final settings in:

`software/acmotion/docs/physical-calibration-template.md`

---

# 6. ESP32-S3 minimum firmware bring-up

Do not begin with ATOM autonomous firmware.

First create/flash a hardware-test firmware able to:

- toggle J1 STEP/DIR;
- toggle J2 STEP/DIR;
- toggle J3 STEP/DIR;
- toggle Z STEP/DIR;
- command the gripper;
- read every endstop;
- report E-stop;
- print state through serial.

Test with motor power disconnected first.

Expected serial diagnostics should identify every input explicitly.

Example conceptual output:

```
J1_LIMIT=0
J2_LIMIT=0
J3_LIMIT=0
Z_LIMIT=0
ESTOP=0
```

---

# 7. Linux preparation on Banana Pi

From repository root:

```bash
bash software/acmotion/scripts/setup_linux.sh
bash software/acmotion/scripts/build_and_test.sh
```

Then run:

```bash
bash software/acmotion/scripts/preflight_linux.sh
```

When ESP32 is connected:

```bash
bash software/acmotion/scripts/preflight_linux.sh /dev/ttyUSB0
```

The actual device may be `/dev/ttyACM0`, `/dev/ttyUSB0`, or another stable udev path.

---

# 8. Verify serial communication with motor power OFF

Run:

```bash
python3 software/acmotion/scripts/serial_monitor.py \
  --device /dev/ttyUSB0 \
  --baud 115200
```

This monitor is read-only.

Confirm:

1. ESP32 boots consistently.
2. Messages are readable.
3. No random resets occur.
4. Endstop changes appear correctly.
5. E-stop state appears correctly.

Do not enable motor power if serial resets when the servo or drivers are connected.

---

# 9. Test the gripper separately

With all steppers disabled:

1. command a conservative open position;
2. command a conservative close position;
3. check current draw;
4. make sure the servo does not remain mechanically stalled;
5. establish safe open/closed percentages.

Record:

- fully open percentage;
- practical piece-grasp percentage;
- mechanical closed limit.

The chess piece should be gripped without continuously forcing the servo against a hard stop.

---

# 10. Test Z axis only

Keep rotary joints disabled.

1. position Z away from both mechanical ends;
2. enable only Z driver;
3. command a very small step count;
4. verify positive direction;
5. reverse;
6. test the Z endstop manually;
7. verify controller stops immediately when expected.

Do not attempt homing at high speed.

Establish:

- Z positive direction;
- home/reference direction;
- steps/mm;
- minimum Z;
- maximum Z.

---

# 11. Test Joint 1 only

Disable J2/J3/Z drivers if practical.

1. move J1 by a very small amount;
2. verify positive direction;
3. reverse;
4. verify belt/pulley motion;
5. test its reference/endstop;
6. measure whether commanded motion approximately matches physical rotation.

Record:

- motor full steps/revolution;
- microstepping;
- belt reduction;
- resulting steps/radian;
- zero offset;
- mechanical limits.

---

# 12. Repeat for Joint 2 and Joint 3

Perform the same procedure independently for J2 and J3.

Do not infer their directions from J1.

The reference robot uses different mechanical reductions between joints, so each axis must have its own conversion/configuration.

---

# 13. Establish homing

Only after every axis works independently:

1. home Z at low speed;
2. home J1;
3. home J2;
4. home J3;
5. back off switches after trigger;
6. establish deterministic zero offsets.

The final order may change after physical testing if one axis can collide during homing.

Document the final homing order in an ADR or firmware runbook.

---

# 14. Measure the real SCARA geometry

Do not use unit-test fixture values such as 100 mm + 100 mm.

Measure from the actual robot/CAD:

- J1 axis center → J2 axis center = L1;
- J2 axis center → relevant distal/tool axis = L2;
- J3/tool geometry;
- tool-center-point offset;
- board plane Z;
- safe Z;
- pick Z.

Also record the angular zero convention of each joint.

---

# 15. Coordinate-frame definition

Define one SCARA base frame.

Recommended documentation must state:

```
origin:
+X:
+Y:
+Z:
positive J1:
positive J2:
positive J3:
tool zero orientation:
```

Do not calibrate the board until these conventions are frozen.

---

# 16. Software IK check

The solver now produces J1/J2/J3/Z targets.

For the configured sign convention:

```
J3 = desired_tool_yaw - J1 - J2 - J3_zero_offset
```

Validate this numerically before powered motion. The measured physical zero/sign convention must match the software configuration; otherwise the tool orientation will be wrong even when XY is correct.

---

# 17. Board calibration

After the arm frame is validated:

1. physically secure the chessboard;
2. define the center of A1;
3. define the center of H1;
4. verify rank direction;
5. configure CoordinateMapper;
6. validate A1/H1/A8/H8/E4.

Do not pick a piece yet.

Move/measure above each target with the tool high above the board.

---

# 18. Safe-height validation

Before picking:

1. command a central square at safe Z;
2. verify XY;
3. lower gradually without a piece;
4. establish pick Z;
5. add clearance margin;
6. verify tallest chess piece does not collide during horizontal travel.

The current MotionPlanner uses separate safe and pick heights.

Use measured values, not defaults, for the physical robot.

---

# 19. First physical pick-and-place

Only after the full four-stepper joint contract and your measured calibration are validated:

1. use one test piece;
2. use two central board squares;
3. disable autonomous Vision/Stockfish/FSM;
4. create one controlled transfer;
5. inspect all Cartesian poses;
6. inspect all J1/J2/J3/Z targets;
7. execute at low speed;
8. keep E-stop accessible;
9. verify every ACK/DONE;
10. measure final error.

Repeat until reliable before enabling captures.

---

# 20. Integration progression

Use this order:

```
single axis
→ homing
→ joint-space move
→ IK target
→ empty-board Cartesian move
→ single-piece pick/place
→ repeated pick/place
→ capture
→ graveyard
→ castling
→ en passant
→ Vision verification
→ Game Coordinator
→ autonomous game
```

Do not jump directly from unit tests to an autonomous chess game.

---

# 21. What to record for every failure

Capture:

- host Git SHA;
- firmware Git SHA;
- measured L1/L2/tool offsets;
- steps/radian or steps/mm;
- microstepping;
- reduction ratios;
- current-limit settings;
- requested Cartesian pose;
- calculated J1/J2/J3/Z;
- ACM command;
- ESP32 response;
- actual physical result;
- endstop/E-stop state.

This information makes a motion bug reproducible instead of hardware-specific guesswork.

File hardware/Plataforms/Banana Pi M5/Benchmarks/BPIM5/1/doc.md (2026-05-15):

# Relatório Final — Desempenho para uso intensivo de visão no braço robótico de xadrez com Banana Pi M5 e OpenCV

---

## 1. Contexto ajustado

O sistema opera sob:

* uso **intensivo de visão computacional**
* processamento contínuo ou quase contínuo de frames
* necessidade de detecção confiável de:

  * tabuleiro
  * ocupação das casas
  * possível identificação de peças

Baseado nos testes:

* alta taxa de sucesso funcional (**~90–100%**)
* falhas concentradas em testes de **desempenho**, não de corretude
* evidência direta de custo elevado em operações geométricas:

```text
TestRemap_remap.remap/191 → ~182 ms
```

* falhas recorrentes em operações paramétricas:

```text
PerfHoughCircles.*
HoughLines (variações de rho/theta/threshold)
```

---

## 2. Impacto do uso intensivo de visão

### Frequência de processamento

* transição de modelo reativo → processamento contínuo

Resultado:

* latência por operação é **aproximadamente estável sob parâmetros fixos**

* porém sensível a:

  * resolução da imagem
  * conteúdo (densidade de bordas/ruído)
  * espaço paramétrico

* carga total passa a ser limitada por:

  * custo por frame
  * throughput efetivo da CPU + memória

---

## 3. Custos dominantes no cenário intensivo

### 3.1 Operações lineares

* **2–8 ms**

Impacto:

* estáveis
* escalam linearmente com resolução
* não representam gargalo relevante

---

### 3.2 Transformações geométricas

* **120–220 ms** (observado ~182 ms)

Evidência:

```text
TestRemap_remap.remap/191 → ~182 ms
```

Impacto:

* principal custo por frame
* acesso irregular à memória → baixa eficiência de cache
* fortemente limitado por bandwidth de memória
* limitador direto de FPS

---

### 3.3 Operações locais

* **1–5 ms**

Impacto:

* desprezível no custo total
* altamente eficientes

---

### 3.4 Classificação leve

* **10–40 ms**

Impacto:

* segundo maior custo no pipeline
* afeta diretamente o throughput em execução contínua

---

### 3.5 Operações paramétricas globais

* **200–500+ ms (ou mais dependendo dos parâmetros)**

Evidência:

```text
PerfHoughCircles.Basic → FAILED
PerfHoughCircles2.ManySmallCircles → FAILED
HoughLines com múltiplas combinações → FAILED
```

Impacto:

* custo cresce com:

  * granularidade de rho/theta
  * threshold
  * densidade de bordas

* comportamento não linear

* múltiplas passagens na imagem → alto custo de memória

Observação:

* não são inviáveis funcionalmente
* são inadequadas para tempo real sem forte restrição de parâmetros

---

## 4. Hierarquia real de custo

1. operações paramétricas globais → pior caso (dependente de parâmetros)
2. transformações geométricas → custo dominante por frame
3. classificação leve → custo relevante
4. operações lineares → custo moderado
5. operações locais → custo baixo

---

## 5. Throughput real sob carga contínua

### Cenário intensivo básico

```text
operações lineares      → ~5 ms
geométrica              → ~120–220 ms
operações locais        → ~2 ms
```

**Total:**
→ **~130–230 ms por frame**

**Resultado:**
→ **~4–7 FPS**

---

### Cenário com classificação leve

```text
base                    → ~130–230 ms
classificação           → +10–40 ms
```

**Total:**
→ **~140–270 ms**

**Resultado:**
→ **~3–6 FPS**

---

### Cenário com múltiplas operações pesadas

```text
base                    → ~130–230 ms
+ geométrica adicional  → +120–220 ms
ou
+ operação global       → +200–500+ ms
```

**Resultado:**

* **2–4 FPS** (geométrica adicional)
* **1–3 FPS** (com operações globais)
* degradação não linear em casos paramétricos

---

## 6. Gargalos estruturais

Principais limitações do hardware:

* acesso irregular à memória (remapeamento)
* baixa eficiência de cache
* múltiplas varreduras em algoritmos globais
* limitação prática de **bandwidth de memória**, não apenas CPU

---

## 7. Sensibilidade de desempenho

### Resolução

* impacto linear direto no tempo total

### Transformações geométricas

* impacto alto e direto no custo por frame

### Espaço de parâmetros

* impacto elevado e não linear
* evidenciado pelas falhas em HoughLines/HoughCircles
* pequenas mudanças podem multiplicar o tempo de execução

---

## 8. Implicações para o braço robótico

### Pontos positivos

* **3–7 FPS** é suficiente para:

  * monitoramento contínuo do tabuleiro
  * detecção de mudanças de estado
  * sincronização com o controle do braço

---

### Limitações reais

* pipeline por frame deve ser curto
* não comporta múltiplas etapas pesadas encadeadas
* sensível a resolução e parâmetros

---

### Risco principal

> O acúmulo de operações com alto custo por frame (especialmente geométricas ou globais) leva à saturação da CPU/memória e perda de responsividade em tempo real.

---

## 9. Condições de viabilidade sob uso intensivo

O sistema permanece viável quando:

* há **no máximo uma transformação geométrica por frame**
* predominam operações **O(N)** e locais
* classificação é leve e controlada
* espaço de parâmetros é restrito

O sistema degrada quando:

* múltiplas transformações geométricas são encadeadas
* algoritmos globais exploram grande espaço paramétrico
* resolução aumenta sem controle

---

## 10. Conclusão final

O Banana Pi M5 suporta uso intensivo de visão computacional com comportamento previsível, porém limitado por memória e operações não locais:

* latência por frame: **130–270 ms**
* throughput contínuo: **~3–7 FPS**

Conclusão objetiva:

> O hardware é viável para o braço robótico de xadrez em regime contínuo, desde que o pipeline de visão seja estritamente controlado. A presença de múltiplas operações de alto custo ou algoritmos com grande espaço paramétrico compromete diretamente o desempenho em tempo real.

---

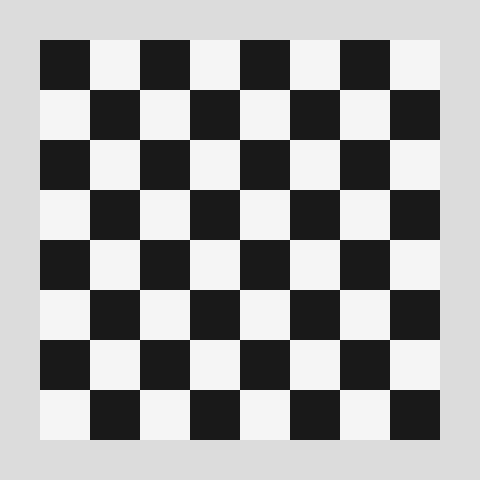
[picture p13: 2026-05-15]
software/acvision/tests/images/chessboard.png

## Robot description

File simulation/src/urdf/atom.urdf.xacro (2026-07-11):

<?xml version="1.0"?>
<robot name="atom_scara" xmlns:xacro="http://www.ros.org/wiki/xacro">

    <material name="atom_blue">
        <color rgba="0.1 0.3 0.8 1.0"/>
    </material>

    <link name="world"/>

    <link name="base_link">
        <visual>
            <origin xyz="0 0 0" rpy="0 0 0"/>
            <geometry>
                <mesh filename="package://atom_description/meshes/base.stl" scale="0.001 0.001 0.001"/>
            </geometry>
            <material name="atom_blue"/>
        </visual>
    </link>

    <joint name="fixed_base" type="fixed">
        <parent link="world"/>
        <child link="base_link"/>
        <origin xyz="0 0 0" rpy="0 0 0"/>
    </joint>

    <link name="z_axis_link">
        <visual>
            <origin xyz="-0.04 0 0" rpy="0 0 0"/>
            <geometry>
                <mesh filename="package://atom_description/meshes/z_axis.stl" scale="0.001 0.001 0.001"/>
            </geometry>
            <material name="atom_blue"/>
        </visual>
    </link>

    <joint name="joint_base_to_link1" type="revolute">
        <parent link="base_link"/>
        <child link="z_axis_link"/>

        <origin xyz="0.04 0 0" rpy="0 0 0"/>

        <axis xyz="0 1 0"/>

        <limit lower="-2.0" upper="2.0" effort="50.0" velocity="3.14"/>
    </joint>

    <link name="arm1_link">
        <visual>
            <origin xyz="-0.04 0 0" rpy="0 0 0"/> 
            <geometry>
                <mesh filename="package://atom_description/meshes/arm1.stl" scale="0.001 0.001 0.001"/>
            </geometry>
            <material name="atom_blue"/>
        </visual>
    </link>

    <joint name="joint_z_axis_arm1" type="prismatic">
        <parent link="z_axis_link"/> 
        <child link="arm1_link"/>
        
        <origin xyz="0.0 0.0 0.0" rpy="0 0 0"/> 
        
        <axis xyz="0 1 0"/> 
        
        <limit lower="-0.1" upper="0.20" effort="50.0" velocity="0.5"/> 
    </joint>

    <link name="arm2_link">
        <visual>
            <origin xyz="-0.26 0 0" rpy="0 0 0"/>
            <geometry>
                <mesh filename="package://atom_description/meshes/arm2.stl" scale="0.001 0.001 0.001"/>
            </geometry>
            <material name="atom_blue"/>
        </visual>
    </link>

    <joint name="joint_arm1_link_arm2_link" type="revolute">
        <parent link="arm1_link"/>
        <child link="arm2_link"/>

        <origin xyz="0.22 0 0" rpy="0 0 0"/>

        <axis xyz="0 1 0"/>

        <limit lower="-2.0" upper="4.0" effort="50.0" velocity="3.14"/>
    </joint>

</robot>

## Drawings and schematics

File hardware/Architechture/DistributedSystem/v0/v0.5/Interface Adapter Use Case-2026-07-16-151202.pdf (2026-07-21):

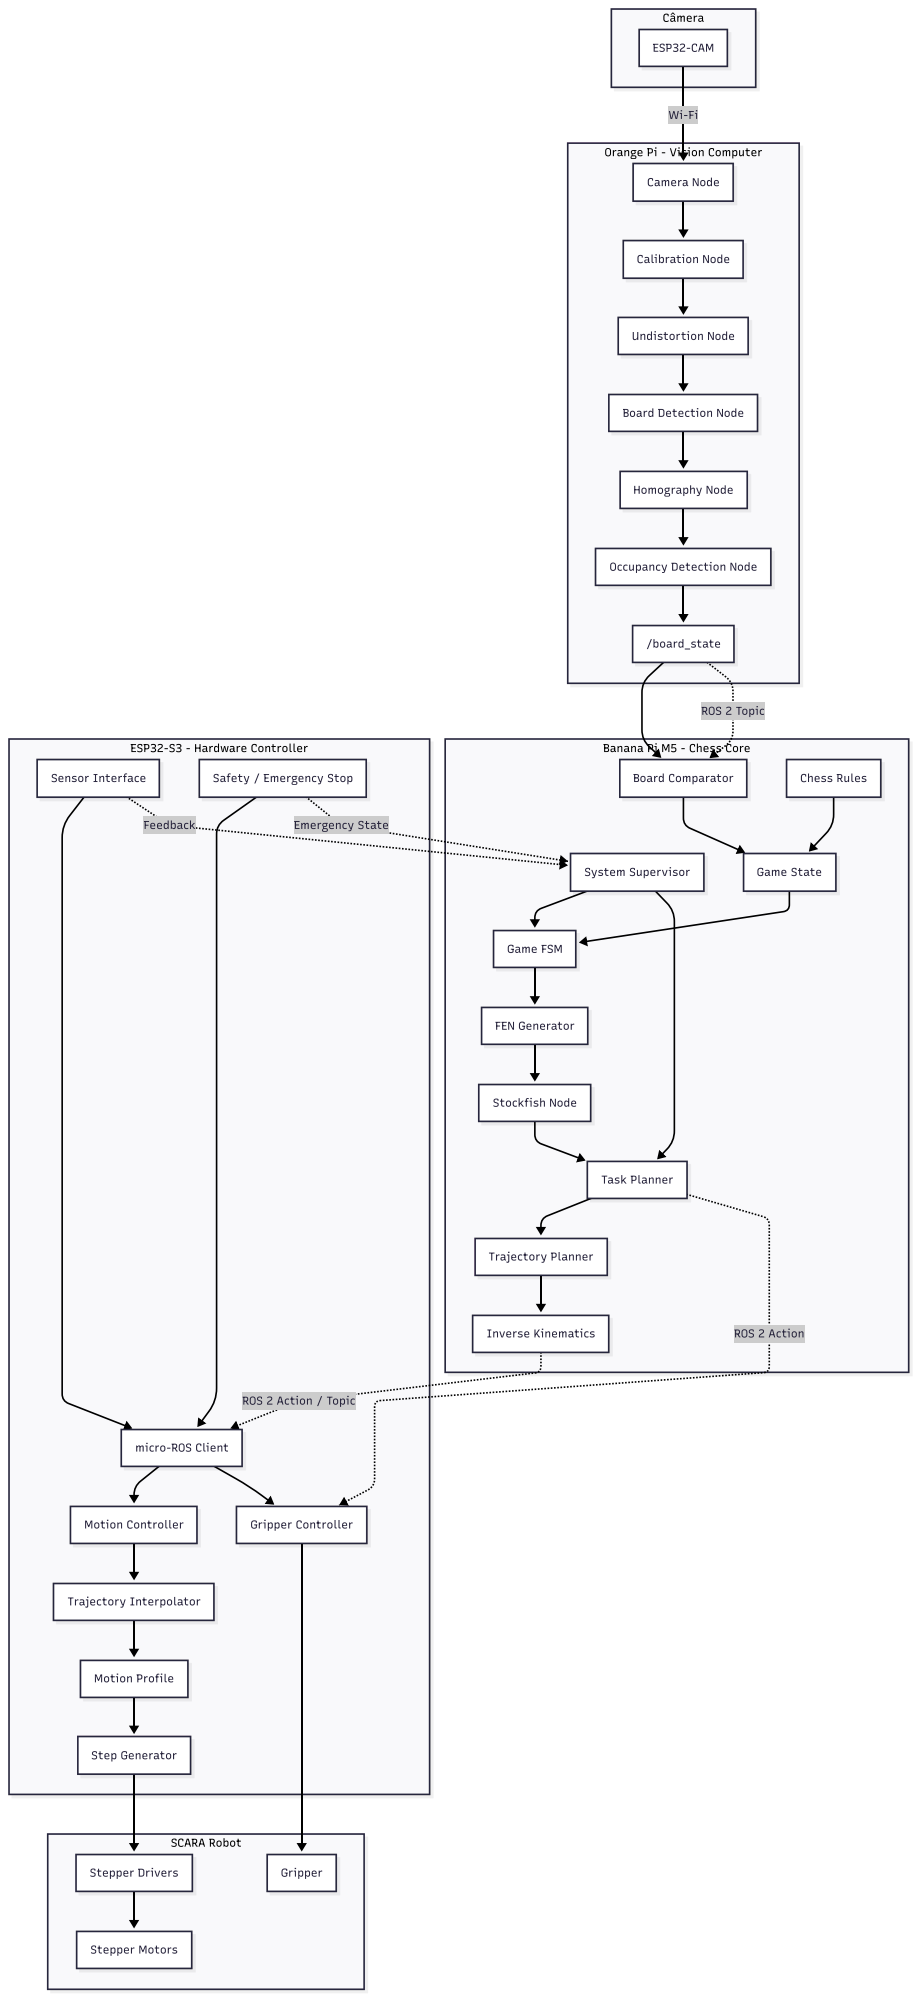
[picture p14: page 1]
SCARA Robot; ESP32-S3 - Hardware Controller; Banana Pi M5 - Chess Core; Câmera; ROS 2 Topic; ROS 2 Action; Feedback; Emergency State; ESP32-CAM; Camera Node; Calibration Node; Undistortion Node; Homography Node; /board_state; Board Comparator; Game State; Game FSM; FEN Generator; Chess Rules; Stockfish Node; Task Planner; Trajectory Planner; Inverse Kinematics; System Supervisor; Motion Controller; Trajectory Interpolator; Motion Profile; Step Generator; Gripper Controller; Sensor Interface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

Orange Pi - Vision Computer

Board Detection Node

Occupancy Detection Node

ROS 2 Action / Topic

micro-ROS Client

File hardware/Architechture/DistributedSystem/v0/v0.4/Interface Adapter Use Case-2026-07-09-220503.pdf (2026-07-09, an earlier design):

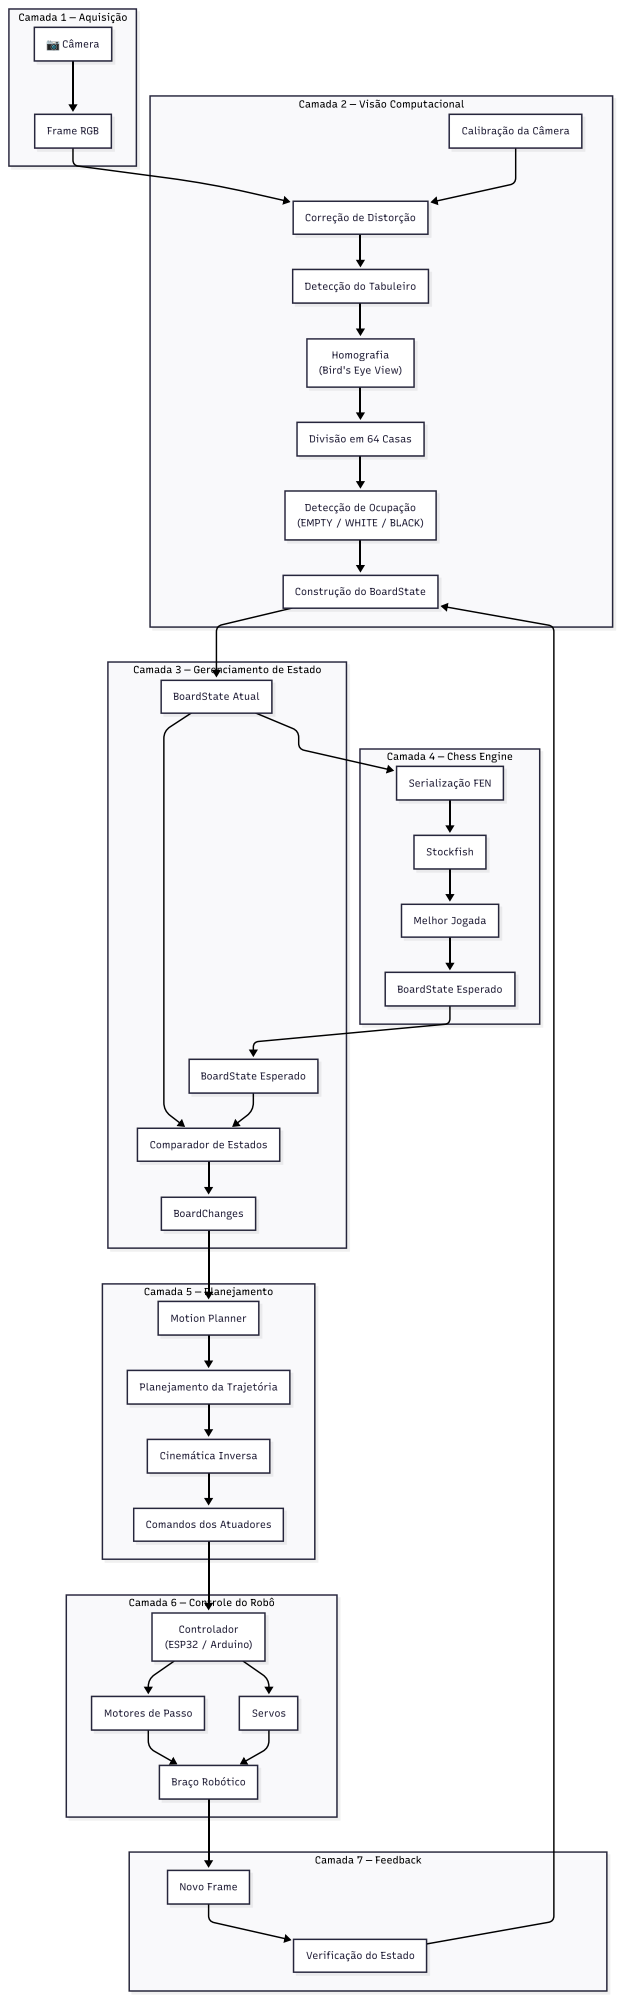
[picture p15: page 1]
Camada 7 — Feedback; Camada 5 — Planejamento; Camada 1 — Aquisição; 📷 Câmera; Frame RGB; Calibração da Câmera; BoardState Atual; BoardChanges; BoardState Esperado; Serialização FEN; Stockfish; Melhor Jogada; Motion Planner; Cinemática Inversa; Controlador; (ESP32 / Arduino); Motores de Passo; Servos; Braço Robótico; Novo Frame

Camada 2 — Visão Computacional

Correção de Distorção

Detecção do Tabuleiro

Homografia
(Bird's Eye View)

Divisão em 64 Casas

Detecção de Ocupação
(EMPTY / WHITE / BLACK)

Construção do BoardState

Camada 3 — Gerenciamento de Estado

Camada 4 — Chess Engine

Comparador de Estados

Planejamento da Trajetória

Comandos dos Atuadores

Camada 6 — Controle do Robô

Verificação do Estado

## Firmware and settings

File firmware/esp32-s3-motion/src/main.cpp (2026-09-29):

#include <Arduino.h>
#include <AccelStepper.h>
#include <ESP32Servo.h>

#include "robot_config.hpp"

namespace {

/**
 * @brief Error codes returned through ACM1 ERR frames.
 */
enum class ErrorCode : int {
    InvalidFrame = 1,
    InvalidNumber = 2,
    NotConfigured = 100,
    EmergencyStop = 101,
    LimitTriggered = 102,
    UnexpectedCommand = 103
};

AccelStepper joint1(AccelStepper::DRIVER,
                atom_motion_config::j1StepPin,
                atom_motion_config::j1DirPin);
AccelStepper joint2(AccelStepper::DRIVER,
                atom_motion_config::j2StepPin,
                atom_motion_config::j2DirPin);
AccelStepper joint3(AccelStepper::DRIVER,
                atom_motion_config::j3StepPin,
                atom_motion_config::j3DirPin);
AccelStepper zAxis(AccelStepper::DRIVER,
                   atom_motion_config::zStepPin,
                   atom_motion_config::zDirPin);
Servo gripper;

/**
 * @brief Returns whether a configurable digital input is active.
 * @param pin GPIO number, or a negative value when the input is unavailable.
 * @param activeLow Whether LOW means asserted.
 * @return true when the configured input is asserted.
 */
bool inputActive(int pin, bool activeLow)
{
    if (pin < 0) {
        return false;
    }

    const int level = digitalRead(pin);
    return activeLow ? level == LOW : level == HIGH;
}

/**
 * @brief Sends one ACM1 response event.
 * @param sequence Host command sequence.
 * @param event ACK, DONE, ESTOP or LIMIT.
 */
void sendEvent(unsigned long sequence, const char* event)
{
    Serial.printf("ACM1|%lu|%s\n", sequence, event);
}

/**
 * @brief Sends one ACM1 error response.
 * @param sequence Host command sequence, zero if frame sequence could not be parsed.
 * @param code Numeric firmware error code.
 */
void sendError(unsigned long sequence, ErrorCode code)
{
    Serial.printf(
        "ACM1|%lu|ERR|%d\n",
        sequence,
        static_cast<int>(code)
    );
}

/**
 * @brief Splits one mutable protocol line in-place.
 * @param line NUL-terminated frame buffer.
 * @param fields Output token pointers.
 * @param maxFields Capacity of fields.
 * @return Number of tokens produced.
 */
size_t splitFields(char* line, char** fields, size_t maxFields)
{
    size_t count = 0;
    char* save = nullptr;
    char* token = strtok_r(line, "|", &save);

    while (token != nullptr && count < maxFields) {
        fields[count++] = token;
        token = strtok_r(nullptr, "|", &save);
    }

    return count;
}

/**
 * @brief Parses a complete finite floating-point field.
 */
bool parseDouble(const char* text, double& value)
{
    char* end = nullptr;
    value = strtod(text, &end);
    return end != text && *end == '\0' && isfinite(value);
}

/**
 * @brief Parses a complete unsigned integer field.
 */
bool parseUnsigned(const char* text, unsigned long& value)
{
    char* end = nullptr;
    value = strtoul(text, &end, 10);
    return end != text && *end == '\0';
}

/**
 * @brief Converts gripper percentage to calibrated servo pulse width.
 */
int gripperPulse(double percent)
{
    const double clamped = constrain(percent, 0.0, 100.0);
    return static_cast<int>(
        atom_motion_config::servoMinUs
        + (atom_motion_config::servoMaxUs - atom_motion_config::servoMinUs)
          * clamped / 100.0
    );
}

/**
 * @brief Stops all four stepper axes immediately.
 */
void stopAxes()
{
    joint1.stop();
    joint2.stop();
    joint3.stop();
    zAxis.stop();
}

/**
 * @brief Returns true when any configured mechanical limit is asserted.
 */
bool anyLimitActive()
{
    return inputActive(
               atom_motion_config::j1LimitPin,
               atom_motion_config::limitsActiveLow
           )
        || inputActive(
               atom_motion_config::j2LimitPin,
               atom_motion_config::limitsActiveLow
           )
        || inputActive(
               atom_motion_config::j3LimitPin,
               atom_motion_config::limitsActiveLow
           )
        || inputActive(
               atom_motion_config::zLimitPin,
               atom_motion_config::limitsActiveLow
           );
}

/**
 * @brief Validates that all safety-critical physical configuration is populated.
 * @return true only when motion pins, conversions and gripper pin are usable.
 */
bool configurationValid()
{
    return atom_motion_config::configured
        && atom_motion_config::j1StepPin >= 0
        && atom_motion_config::j1DirPin >= 0
        && atom_motion_config::j2StepPin >= 0
        && atom_motion_config::j2DirPin >= 0
        && atom_motion_config::j3StepPin >= 0
        && atom_motion_config::j3DirPin >= 0
        && atom_motion_config::zStepPin >= 0
        && atom_motion_config::zDirPin >= 0
        && atom_motion_config::gripperServoPin >= 0
        && atom_motion_config::j1StepsPerRad > 0.0
        && atom_motion_config::j2StepsPerRad > 0.0
        && atom_motion_config::j3StepsPerRad > 0.0
        && atom_motion_config::zStepsPerMm > 0.0
        && atom_motion_config::maxStepperSpeed > 0.0
        && atom_motion_config::stepperAcceleration > 0.0;
}

/**
 * @brief Polls the serial stream for cancellation while a segment is executing.
 * @param activeSequence Sequence currently executing.
 * @return true when a matching ACM1 CANCEL frame was received.
 *
 * Only cancellation is accepted during active motion. Additional SEG commands
 * are rejected instead of being executed re-entrantly.
 */
bool cancellationRequested(unsigned long activeSequence)
{
    static char cancelLine[96];
    static size_t cancelUsed = 0;

    while (Serial.available() > 0) {
        const char ch = static_cast<char>(Serial.read());

        if (ch == '\n') {
            cancelLine[cancelUsed] = '\0';
            if (cancelUsed > 0 && cancelLine[cancelUsed - 1] == '\r') {
                cancelLine[cancelUsed - 1] = '\0';
            }

            char* fields[4]{};
            const size_t count = splitFields(cancelLine, fields, 4);
            cancelUsed = 0;

            unsigned long sequence = 0;
            if (count == 3
                && strcmp(fields[0], "ACM1") == 0
                && parseUnsigned(fields[1], sequence)
                && strcmp(fields[2], "CANCEL") == 0) {
                if (sequence == activeSequence) {
                    return true;
                }

                sendError(sequence, ErrorCode::UnexpectedCommand);
                continue;
            }

            sendError(activeSequence, ErrorCode::UnexpectedCommand);
            continue;
        }

        if (cancelUsed + 1 < sizeof(cancelLine)) {
            cancelLine[cancelUsed++] = ch;
        } else {
            cancelUsed = 0;
            sendError(activeSequence, ErrorCode::InvalidFrame);
        }
    }

    return false;
}

/**
 * @brief Executes one four-axis joint target after ACM1 validation.
 *
 * This is intentionally a conservative blocking MVP executor. Each axis uses
 * AccelStepper acceleration limits. Future synchronized profiles may replace
 * this implementation without changing the host chess-domain boundary.
 */
bool executeSegment(
    unsigned long sequence,
    double j1Rad,
    double j2Rad,
    double j3Rad,
    double zMm,
    double gripperPercent,
    unsigned long durationMs)
{
    if (!configurationValid()) {
        sendError(sequence, ErrorCode::NotConfigured);
        return false;
    }

    if (inputActive(
            atom_motion_config::emergencyStopPin,
            atom_motion_config::emergencyStopActiveLow)) {
        sendEvent(sequence, "ESTOP");
        return false;
    }

    const long j1Target = lround(j1Rad * atom_motion_config::j1StepsPerRad);
    const long j2Target = lround(j2Rad * atom_motion_config::j2StepsPerRad);
    const long j3Target = lround(j3Rad * atom_motion_config::j3StepsPerRad);
    const long zTarget = lround(zMm * atom_motion_config::zStepsPerMm);

    joint1.moveTo(j1Target);
    joint2.moveTo(j2Target);
    joint3.moveTo(j3Target);
    zAxis.moveTo(zTarget);

    const double durationSeconds = max(0.001, durationMs / 1000.0);
    const auto setSegmentSpeed = [durationSeconds](AccelStepper& axis) {
        const double required =
            abs(axis.distanceToGo()) / durationSeconds;
        axis.setMaxSpeed(
            min(required, atom_motion_config::maxStepperSpeed)
        );
    };

    setSegmentSpeed(joint1);
    setSegmentSpeed(joint2);
    setSegmentSpeed(joint3);
    setSegmentSpeed(zAxis);

    gripper.writeMicroseconds(gripperPulse(gripperPercent));

    sendEvent(sequence, "ACK");

    while (joint1.distanceToGo() != 0
           || joint2.distanceToGo() != 0
           || joint3.distanceToGo() != 0
           || zAxis.distanceToGo() != 0) {
        if (cancellationRequested(sequence)) {
            stopAxes();
            sendEvent(sequence, "DONE");
            return false;
        }

        if (inputActive(
                atom_motion_config::emergencyStopPin,
                atom_motion_config::emergencyStopActiveLow)) {
            stopAxes();
            sendEvent(sequence, "ESTOP");
            return false;
        }

        if (anyLimitActive()) {
            stopAxes();
            sendEvent(sequence, "LIMIT");
            return false;
        }

        joint1.run();
        joint2.run();
        joint3.run();
        zAxis.run();
        yield();
    }

    sendEvent(sequence, "DONE");
    return true;
}

/**
 * @brief Parses and dispatches one complete ACM1 line.
 */
void handleFrame(char* line)
{
    char* fields[10]{};
    const size_t count = splitFields(line, fields, 10);

    if (count < 3 || strcmp(fields[0], "ACM1") != 0) {
        sendError(0, ErrorCode::InvalidFrame);
        return;
    }

    unsigned long sequence = 0;
    if (!parseUnsigned(fields[1], sequence) || sequence == 0) {
        sendError(0, ErrorCode::InvalidNumber);
        return;
    }

    if (strcmp(fields[2], "CANCEL") == 0 && count == 3) {
        stopAxes();
        sendEvent(sequence, "DONE");
        return;
    }

    // ACM1|seq|SEG|j1|j2|j3|z|gripper|duration
    if (strcmp(fields[2], "SEG") != 0 || count != 9) {
        sendError(sequence, ErrorCode::InvalidFrame);
        return;
    }

    double j1Rad = 0.0;
    double j2Rad = 0.0;
    double j3Rad = 0.0;
    double zMm = 0.0;
    double gripperPercent = 0.0;
    unsigned long durationMs = 0;

    if (!parseDouble(fields[3], j1Rad)
        || !parseDouble(fields[4], j2Rad)
        || !parseDouble(fields[5], j3Rad)
        || !parseDouble(fields[6], zMm)
        || !parseDouble(fields[7], gripperPercent)
        || !parseUnsigned(fields[8], durationMs)
        || durationMs == 0
        || gripperPercent < 0.0
        || gripperPercent > 100.0) {
        sendError(sequence, ErrorCode::InvalidNumber);
        return;
    }

    (void)executeSegment(
        sequence,
        j1Rad,
        j2Rad,
        j3Rad,
        zMm,
        gripperPercent,
        durationMs
    );
}

} // namespace

void setup()
{
    Serial.begin(115200);

    const auto configureInput = [](int pin) {
        if (pin >= 0) {
            pinMode(pin, INPUT_PULLUP);
        }
    };

    configureInput(atom_motion_config::j1LimitPin);
    configureInput(atom_motion_config::j2LimitPin);
    configureInput(atom_motion_config::j3LimitPin);
    configureInput(atom_motion_config::zLimitPin);
    configureInput(atom_motion_config::emergencyStopPin);

    joint1.setPinsInverted(atom_motion_config::j1InvertDirection);
    joint2.setPinsInverted(atom_motion_config::j2InvertDirection);
    joint3.setPinsInverted(atom_motion_config::j3InvertDirection);
    zAxis.setPinsInverted(atom_motion_config::zInvertDirection);

    for (AccelStepper* axis : {&joint1, &joint2, &joint3, &zAxis}) {
        axis->setMaxSpeed(atom_motion_config::maxStepperSpeed);
        axis->setAcceleration(atom_motion_config::stepperAcceleration);
    }

    if (atom_motion_config::gripperServoPin >= 0) {
        gripper.attach(
            atom_motion_config::gripperServoPin,
            atom_motion_config::servoMinUs,
            atom_motion_config::servoMaxUs
        );
    }

    Serial.println(
        configurationValid()
            ? "ATOM_MOTION_READY"
            : "ATOM_MOTION_CONFIG_REQUIRED"
    );
}

void loop()
{
    static char line[192];
    static size_t used = 0;

    while (Serial.available() > 0) {
        const char ch = static_cast<char>(Serial.read());

        if (ch == '\n') {
            line[used] = '\0';
            if (used > 0 && line[used - 1] == '\r') {
                line[used - 1] = '\0';
            }
            handleFrame(line);
            used = 0;
            continue;
        }

        if (used + 1 < sizeof(line)) {
            line[used++] = ch;
        } else {
            used = 0;
            sendError(0, ErrorCode::InvalidFrame);
        }
    }
}

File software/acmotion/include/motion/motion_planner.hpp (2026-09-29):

#ifndef ACMOTION_MOTION_PLANNER_HPP
#define ACMOTION_MOTION_PLANNER_HPP

#include <string>
#include <vector>

#include "motion/coordinate_mapper.hpp"
#include "motion/physical_task.hpp"

namespace ac::motion {

/**
 * @enum PredefinedPosition
 * @brief Stable non-board poses used by high-level motion flows.
 */
enum class PredefinedPosition {
    HOME,        ///< Neutral parking pose away from the board.
    SAFE_STAGING ///< Generic high-clearance staging pose.
};

/**
 * @struct Pose
 * @brief One Cartesian manipulation waypoint in the SCARA base frame.
 *
 * Position uses millimetres. toolYawRad expresses desired planar end-effector
 * orientation in radians and is used to solve the distal J3 axis on the
 * How To Mechatronics SCARA.
 */
struct Pose {
    double x{0.0};               ///< X coordinate in millimetres.
    double y{0.0};               ///< Y coordinate in millimetres.
    double z{0.0};               ///< Z coordinate in millimetres.
    double gripperPercent{0.0};  ///< 0 = closed, 100 = fully open.
    std::string label;           ///< Diagnostic label for logs/tracing.
    double toolYawRad{0.0};      ///< Desired planar tool orientation in radians in the SCARA base frame.
};

/**
 * @class MotionPlanner
 * @brief Expands one physical transfer into an ordered pick-and-place trajectory.
 *
 * MotionPlanner runs on the Linux SBC. It consumes calibrated Cartesian
 * coordinates and generates high-level poses. It does not interpolate step
 * pulses, access GPIO, or drive motors directly; those responsibilities belong
 * to the ESP32-S3 motion controller.
 */
class MotionPlanner {
public:
    /**
     * @brief Constructs a planner using calibrated board geometry.
     * @param mapper Coordinate mapper used by planBoardMove().
     * @param safeHeightZ Collision-clearance height in millimetres.
     * @param pickHeightZ Grasp/release height in millimetres.
     *
     * @throws std::invalid_argument when safeHeightZ is not above pickHeightZ,
     *         or when either height is non-finite.
     * @note mapper must outlive this planner.
     */
    MotionPlanner(
        const CoordinateMapper& mapper,
        double safeHeightZ = 50.0,
        double pickHeightZ = 10.0
    );

    /**
     * @brief Plans a pick-and-place transfer between two physical XY points.
     * @param source Physical source coordinate in the SCARA base frame.
     * @param target Physical destination coordinate in the SCARA base frame.
     * @return Eight ordered poses: approach, lower, grasp, lift, travel, lower,
     *         release, retract.
     *
     * @throws std::invalid_argument when either point contains non-finite values.
     */
    [[nodiscard]] std::vector<Pose> planTransfer(
        Point2D source,
        Point2D target
    ) const;

    /**
     * @brief Plans a transfer between two algebraic board squares.
     * @param from Source square such as "e2".
     * @param to Target square such as "e4".
     * @return Same eight-pose sequence produced by planTransfer().
     *
     * @throws std::runtime_error when board geometry is not calibrated.
     * @throws std::invalid_argument when notation is invalid.
     */
    [[nodiscard]] std::vector<Pose> planBoardMove(
        const std::string& from,
        const std::string& to
    ) const;

    /**
     * @brief Expands one high-level PhysicalTask into a pick-and-place trajectory.
     * @param task Task produced by TaskPlanner.
     * @return Eight-pose transfer trajectory for MoveBoardPiece or RemoveCapturedPiece.
     *
     * @throws std::invalid_argument when a transfer task lacks physical endpoints,
     *         or when task.type is PromotionRequired.
     *
     * @note PromotionRequired is intentionally not converted into motion until
     *       the project defines concrete promotion replacement hardware.
     */
    [[nodiscard]] std::vector<Pose> planTask(
        const PhysicalTask& task
    ) const;

    /**
     * @brief Returns one stable predefined pose.
     * @param position Desired predefined target.
     * @return Cartesian pose associated with the requested position.
     */
    [[nodiscard]] Pose getPredefinedPose(PredefinedPosition position) const;

private:
    /**
     * @brief Validates that a 2D physical point is finite.
     * @param point Coordinate to validate.
     * @throws std::invalid_argument when X or Y is NaN/inf.
     */
    static void validatePoint(Point2D point);

    const CoordinateMapper& mapper_; ///< Calibrated board geometry.
    double safeHeightZ_;             ///< Collision-clearance height in mm.
    double pickHeightZ_;             ///< Grasp/release height in mm.

    static constexpr double GRIPPER_OPEN = 100.0; ///< Fully open gripper command percentage.
    static constexpr double GRIPPER_CLOSED = 0.0; ///< Fully closed gripper command percentage.

    /** @brief Default neutral parking pose used outside active manipulation. */
    const Pose HOME_POSE{
        0.0, 0.0, 150.0, GRIPPER_OPEN, "HOME"
    };

    /** @brief Default high-clearance staging pose used during safe repositioning. */
    const Pose SAFE_STAGING_POSE{
        0.0, 0.0, 100.0, GRIPPER_OPEN, "SAFE_STAGING"
    };
};

} // namespace ac::motion

#endif

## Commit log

2026-03-19 Add readme with instructions; fix folder names. (#22)
    * Create Frame Capture.cpp
    Code for frame capturing with camera streaming.
    Commented: Frame capture without streaming.
    * Update README com instruções para realizar instalações do OpenCV e testar a camera
    Added detailed instructions for setting up OpenCV and Visual Studio.
    * Rename README.MD to README.md
    * Update README with HTML formatting and structure
    * Add README, update files and folders.
    * Update README.md
2026-03-20 Add acvision camera module, apps, tests and tooling
    Introduce a new Software/acvision CMake project and developer tooling for camera capture. Adds a shared library (acvision) with camera header and implementation (capture_frame using CAP_DSHOW), a cap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
2026-03-20 Introduce ac::Camera class and update GUI usage
    Replace the previous stateless capture approach with a persistent ac::Camera RAII wrapper. Added Camera class (constructor, destructor, capture_frame(), is_opened()) in camera.hpp and implemented it in camera.cpp using cv::CAP_DSHOW and explicit resource release; improved documentation and error logging. Updated capture_gui.cpp to instantiate ac::Camera(0) and call camera.capture_frame() instead of the old capture_frame(0) free function. Note: this is an API change (no more free capture_frame(int)); callers must create and reuse an ac::Camera instance. The Camera class is non-copyable and not thread-safe (calls must be externally synchronized).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
2026-03-20 Use camera resolution & EMA FPS overlay
    Add width/height parameters to Camera ctor (default 1280x720) and set/query actual resolution when the capture opens. Update capture_gui to construct Camera(0, 640, 480), early-exit if the camera isn't opened, replace the old FPS counter with per-frame latency and an exponential moving average (alpha=0.1) FPS, and display both latency and EMA FPS with drop-shadowed overlays. Also simplify event handling and remove the file header/comment and some redundant logs.
2026-03-26 Add chess piece detector and FEN generator
    Introduce vision module components: PieceDetector and FenGenerator. PieceDetector (header + impl) analyzes an 8x8 array of cv::Mat cell images and classifies each cell as EMPTY, WHITE, or BLACK using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
2026-03-27 Refactor CMake, add tests & camera backend
    Modernize and reorganize the acvision build and camera code:
    - Bump cmake minimum to 3.23 and add project description; set C++17, disable extensions, and conditionally enable Windows export symbols.
    - Replace hardcoded OpenCV path usage with find_package and link explicit OpenCV components (core/imgproc/highgui/videoio).
    - Add target_sources for public headers and set stricter compiler warnings for MSVC/others.
    - Automate application target generation (apps) and test target generation (tests) with folder grouping; copy OpenCV runtime DLLs on Windows after build.
    - Add CMakePresets.json and CmakeUserPresets.json to simplify local/configurable builds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
2026-04-03 feat(app): add board detection demo application
2026-04-03 build: add board detection module to CMake configuration
2026-04-04 Restructure acvision sources; add tests
    Move piece_detector and fen_generator headers/sources into dedicated subdirectories, update includes and CMakeLists to register the moved files and add corresponding tests. Replace implicit int conversions in PieceDetector::extractCenterROI with explicit static_cast<int>. Add unit tests for FenGenerator and PieceDetector to validate FEN generation and basic piece/color detection over the 8x8 board.
2026-04-05 Add simulator app and CMake simulation target
    Add a new simulation executable and integrate it into the build system, plus related dev-environment tweaks.
    - Add Software/acvision/simulation/simulator.cpp: a simple synthetic board simulator that uses ac::PieceDetector to analyze an 8x8 board and displays the result.
    - Update Software/acvision/CMakeLists.txt: automatic target generation for the "simulator" executable, links against acvision, sets FOLDER property, and adds a Windows post-build step to copy OpenCV runtime DLLs.
    - Update .vscode/settings.json: set "cmake.useCMakePresets" to "never" to avoid using presets on configure.
    - Update Software/acvision/CMakePresets.json: set C and C++ c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
2026-04-05 Revamp README, add setup script, enable presets
    Refactors Software/acvision/README.md to focus on a Windows/MSVC-centric workflow: reorganizes sections (requirements, OpenCV, environment setup, terminal build flow, daily workflow, and troubleshooting), clarifies OpenCV_DIR/ PATH expectations, and advises building via terminal rather than the VSCode CMake Tools. Updates .vscode/settings.json to enable CMake presets. Adds setup_env.bat to call vcvars64.bat, remove a conflicting Strawberry path entry from PATH, and verify cl/link/ninja are available. These changes aim to simplify developer setup and avoid common MSVC/OpenCV/VSCode kit mismatches.
2026-04-08 Enhance documentation for board_detection_demo.cpp
    Added detailed documentation for the board detection demo application, explaining its purpose and functionality.
2026-04-08 Document BoardCorners structure
    Added documentation for BoardCorners structure.
2026-04-08 Add documentation for board_detector.cpp
    Added documentation for the BoardDetector class and its detect method.
2026-04-08 translate board_detection module documentation from ptbr to en
    changed all documentation, and docstrings from portguese to english
2026-04-14 refactor: update board detector paths after module reorganization
2026-05-14 test(acvision): add board detector image tests
2026-07-09 Create Interface Adapter Use Case-2026-07-09-220503.pdf
2026-07-10 Create Interface Adapter Use Case-2026-07-10-154931.pdf
2026-07-10 add banana pi
    [SCARA Robot.f3d]
2026-07-11 add RViz2 vizualization of model
    [arm1.stl, arm2.stl, atom.urdf.xacro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]
2026-07-11 Merge pull request #78 from Atom-Laboratory/feature/geometria-tabuleiro
    feat: implementa homografia, normalizacao e segmentacao 8x8 (#14, #15…
    [SCARA Robot.f3d, arm1.stl, arm2.stl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]
2026-07-13 test: refactor board geometry test to use real image and BoardDetector class
2026-07-13 Revert "."
    This reverts commit edcc222406862f603c5c865bcebb66c19a2b256a.
    revert
    [SCARA Robot.f3d]
2026-07-16 add stl files
    [ARDUINO-UNO-CASE-PT1-AND-PT2.3mf, ARM1-AND-ARM1-COVER.3mf, ARM2-AND-ARM2-COVER.3mf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]
2026-07-16 feat: implement initial BoardState and Piece structures
2026-07-23 fix: guard FPS calculation against tiny frame deltas
2026-07-23 fix: inclui board_state.hpp no CMakeLists
2026-07-28 fix(board): corrige iterador no loop de clear (Issue #89)
2026-07-28 refactor: move estruturas para o namespace ac::chess e remove duplicatas da visao
2026-07-28 docs: adiciona docstring na classe Board
2026-07-30 test: adiciona testes unitarios da classe Board (Issue #93) e corrige namespaces no renderer
2026-07-30 wip: progresso salvo antes de pausar a refatoracao do fen_generator
2026-07-30 refactor(acmotion): add ac::motion namespace, doxygen docs, and gripper percentage
2026-07-30 fix: implementa operadores de comparacao, makeMove, geracao correta de FEN e finaliza testes
2026-08-03 refactor(board): keep move application outside Board
2026-08-03 feat(board): add MoveApplier for board state updates
2026-08-03 refactor(board): delegate legacy makeMove to MoveApplier
2026-08-03 test(board): cover board state updates
2026-08-03 feat(board): add board state comparator
2026-08-03 test(board): cover board state differences
2026-08-03 build(test): register BoardComparator tests
2026-08-03 add note explaining the 'nodiscard' attribute in BoardComarator::compare method.
2026-08-03 add note to the reserve(4) line in board_comparator.cpp
2026-08-04 refactor: migra Stockfish para o modulo acchess, documenta IPC e atualiza testes
2026-08-06 fix: adiciona tratamento de erro no retorno do IPC do Stockfish (closes #101)
2026-08-15 fix(board): harden board state integration
2026-08-30 Add repository governance docs
    This commit adds repository governance and contribution tooling with CODEOWNERS, PR/review templates, and a contribution guide. It also updates the README to better describe ATOM Laboratory, project 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
    [ARDUINO-UNO-CASE-PT1-AND-PT2.3mf, ARM1-AND-ARM1-COVER.3mf, ARM2-AND-ARM2-COVER.3mf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]
2026-09-26 fix(board): iterate over rows correctly in clear
2026-09-26 fix(board): iterate over current row in clear
2026-09-26 fix(cmake): wire tests into CTest (#106)
    Enable root/standalone CTest, keep camera tests opt-in, decouple deterministic chess tests from Stockfish, add GoogleTest fallback, support headless viewer-off builds, and document the test architecture.
2026-09-26 Fix link case sensitivity for CONTRIBUTING.md
2026-09-26 fix(camera): handle multi-channel intensity safely (#116)
    Separate deterministic frame-processing tests from physical-camera tests and keep the implementation suitable for headless Linux SBC targets.
2026-09-26 refactor(vision): introduce BoardObservation boundary (#112)
    Separate visual board observations from authoritative chess state and preserve a headless Linux SBC-compatible API.
2026-09-26 feat(vision): benchmark real PieceDetector pipeline (#110)
    Run the 57-image dataset through real board detection, homography and PieceDetector and report observation-level accuracy metrics.
2026-09-26 fix(motion): restore safe gripper pick sequence
2026-09-26 feat(vision): persist optional PieceDetector calibration (#113)
    Persist HSV color profiles for headless SBC runtime while keeping calibration GUI outside the production path.
2026-09-26 refactor(motion): reapply CoordinateMapper on current main
2026-09-26 feat(motion): add CoordinateMapper on current main
2026-09-26 fix(motion): repair CoordinateMapper calibration serialization
2026-09-26 Revert "feat(acmotion): implement 2x8 graveyard matrices and unit tests"
    [motion_planner.hpp]
2026-09-26 docs(chess): restore board and test documentation
2026-09-27 fix(acchess): enforce board domain invariants
2026-09-27 feat(acchess): add authoritative FEN metadata to Board
2026-09-27 feat(acchess): implement Board metadata state
2026-09-27 feat(motion): integrate graveyard allocator (#145)
    Use the final acchess Piece model and CoordinateMapper-backed physical Graveyard slots with explicit CMake dependencies.
2026-09-27 docs(acchess): fully document Board state and FEN metadata
2026-09-27 test(acchess): update Board integration FEN expectation
2026-09-27 docs(acchess): document Board internal square validation
2026-09-27 docs(motion): complete GraveyardAllocator Doxygen (#147)
    Document SBC/ESP32 boundaries, allocation invariants, parameters, return values and exceptions for GraveyardAllocator.
2026-09-27 refactor(motion): replace production CoordinateMapperMock
    [motion_planner.hpp]
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2026-09-28 fix(motion): preserve graveyard state on planning failure
    Resolve structural invariants and calibrated board coordinates before
    allocating a graveyard slot. Add regression coverage proving that failed
    plans do not consume capacity and verify mapped coordinates for a normal move.
2026-09-29 fix(motion): add Dejan SCARA J3 support end-to-end (#162)
    Add J3 to Pose/IK/joint targets/ACM1, add four-axis ESP32-S3 reference firmware, update CI and physical integration documentation, and resolve #160.
    [main.cpp, motion_planner.hpp]
2026-10-06 feat(integration): interpret BoardObservation into validated chess moves (#151)
2026-11-01 fix(integration): validate board observations before committing moves
